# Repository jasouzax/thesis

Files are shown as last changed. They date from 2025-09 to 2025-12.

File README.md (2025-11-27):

# Thesis of Jasouza
 
 
[]() 
 
 
 

Development of Visual [Sensory Substitution Device](https://en.wikipedia.org/wiki/Sensory_substitution) for the visually impared especially the blind, through incorporating three novel ideas to solve issues of existing solutions: Virtual World Mapping, Emulating Human Sensoring, and Adaptable Modular System
- [Title](#title)
- [Background of the Study](#background-of-the-study)
- [Rationale](#rationale)

### Summary
1. **Identifying a Problem**  
   The thesis identifies a problem aligned with global frameworks, such as the Sustainable Development Goals (SDGs), to ensure relevance and real-world impact. Specifically, it focuses on **SDG 10: Reduced Inequalities**, which targets disparities based on factors like income, age, sex, disability, race, ethnicity, origin, religion, or economic status. To narrow the scope, the work concentrates on **disability inequalities, with an emphasis on visual impairments** (e.g., blindness or low vision, affecting over 2.2 billion people per WHO estimates).

2. **Identifying the Objective**  
   Drawing from SDG 10, the primary objective is to **minimize inequalities faced by visually impaired individuals**. These fall into two major, often overlapping categories:  
   - **Navigational inequalities**: Barriers in physical and digital infrastructure not designed for accessibility (e.g., buildings without tactile guides or websites lacking audio alternatives).  
   - **Social inequalities**: Limitations in communication, societal status, or workforce participation (e.g., reduced job opportunities due to inaccessible tools or stigma in social interactions).  
   Note that inequalities are not strictly binary; for instance, job opportunities can involve both navigational challenges (e.g., vision-dependent tasks) and social ramifications (e.g., financial limitations from restricted options), aligning with SDG targets like 10.1 (reducing income inequalities through broader employment access), 10.2 (promoting social, economic, and political inclusion), and 10.3 (ensuring equal opportunities despite barriers like discrimination).

3. **Identifying a Solution**  
   Approaches to addressing these inequalities are not mutually exclusive and can blend elements, though they often prioritize one aspect:  
   - **Assistive technologies**, which primarily extend existing capabilities (e.g., canes, guide dogs, or braille displays).  
   - **Substitution technologies**, which primarily represent missing senses through alternatives (e.g., screen readers or sensory substitution devices that convert visual data to audio/tactile feedback).  
   The thesis prioritizes the **substitution approach** due to its potential for comprehensive impact on the identified objectives, enabling more independent navigation and interaction, while acknowledging that hybrid solutions may incorporate assistive elements.

4. **Identifying the Issues**  
   Substitution technologies, particularly sensory substitution devices (SSDs), encounter significant, interconnected challenges generalized as **sensory limitations**:  
   - **Sensory overload**: When translated information exceeds the brain's processing capacity.  
   - **Sensory fatigue**: Prolonged use leading to mental exhaustion.  
   - **Sensory integration**: Difficulty in learning or subconsciously interpreting the substituted signals.  
   These stem from the core limitation of representing one sense through another and must be addressed for effective adoption.

5. **Identifying our Hypothesis**  
   Inspired by human psychology—where perception is **selective rather than raw data intake**—the hypothesis posits that SSDs can minimize sensory limitations by making the process **controllable**. This allows the brain to build subconscious patterns efficiently. For the prototype, users could control the "focus" of emulated vision via **silent, quick inputs like hand gestures**, mimicking eye muscle adjustments. However, the core focus is on controllability itself, with the method being modular (e.g., adaptable to voice, head tilts, or eye-tracking for users with varying abilities) to suit the hypothesis without restricting to one input type.

6. **Identifying the Tests**  
   To validate the hypothesis, evaluate the device's efficiency in mitigating sensory limitations through a mix of quantitative and qualitative metrics:  
   - **Sensory overload**: Measure user accuracy in interpreting generated audio cues (e.g., via task completion rates) and qualitative feedback on perceived overload.  
   - **Sensory fatigue**: Assess usage duration before symptoms like headaches emerge (e.g., via self-reported scales, physiological monitoring, or user surveys).  
   - **Sensory integration**: Track reaction times to environmental data, learning curves over sessions, and survey responses on ease of subconscious adaptation.  
   - **Device performance**: Test accuracy in recognizing user controls (e.g., hand gestures) and generating relevant audio from environmental inputs.  
   Evaluations will include comparisons to baselines from related literature on existing SSDs, incorporating user-centered qualitative insights (e.g., surveys) to account for individual experiences.

7. **Identifying the Impact**  
   If successful, the device could substitute visual information as audio via a **modular pipeline**, enabling extensions for diverse needs (e.g., customizable adaptations for varying lifestyles or impairment levels). This would reduce navigational inequalities (e.g., accessible OS and environments for better job opportunities) and social inequalities (e.g., enhanced communication tools), contributing to SDG 10 targets such as 10.1 (income growth via expanded employment), 10.2 (empowerment through regained navigational and social inclusion), and 10.3 (equal opportunities in workforce and society). While not resolving all issues (e.g., medical treatments or systemic discrimination), it demonstrates the possibility of partially minimizing sensory limitations—evidenced by test results showing users can interpret data with reduced overload, fatigue, or integration challenges—paving the way for applications to other sensory disabilities.

8. **Identifying the Scope and Limitations**  
   The thesis prioritizes proving the hypothesis—that sensory limitations can be partially addressed through selective, controllable substitution—rather than perfecting the device or developing all extensions. By completion, the output will be a prototype SSD that emulates visual perception as audio, minimizes limitations, and features a modular pipeline for future enhancements (e.g., alternative controls). Limitations include assumptions of basic user abilities for prototype inputs, focus on visual-to-audio substitution only, and recognition that tech complements broader efforts like policy changes for full inequality reduction.

<!--
## Summary
- [**Problem**](https://pmc.ncbi.nlm.nih.gov/articles/PMC5044782) - Issue facing visual sensory substitution devices in widespread adoption that being **cognitive overload** and **limited generaliziblity**.
- **Solution** - To **emulate human visual attention** to solve cognitive overload, and to implement a **virtual navigatable world system** to solve limited generaliziblity.
- **Hypothesis** - Would emulating *human visual processes* to minimize substituted information and implementing *navigation techniques to virtual worlds (physical and digital)* prevent cognitive overload, allow subconscious sensory augmentation, and help integrate visually impared individuals in the physical and digital aspects?
   - [**Null Hypothesis**](https://en.wikipedia.org/wiki/Null_hypothesis) $H_0$ - The solution we implemented provided did not prevent cognitive overload nor help individuals navigate both physical and digital worlds.
   - **Alternative Hypothesis** $H_1$ - The solution we implemented forwarded the progress of sensory substitution devices by solving the two issues facing most sensory substitution devices.
   - **P-Value Testing** - Quantitative testing such has accuracy of individual's pointing to direction of movement, and Qualitative testing (Focus Group Discussion (FGD)) such as how much of them sense through the device subconsciously.

## Timeline to take note of
Vietnam field trip, Service Learning, and [Robothia Conference on Robotics and Technologies](https://www.ihsanyassin.com/cms/conference.php?conf_id=883736a8-1285-42f8-95f5-dd1f653de3f6)
- `Nov 24, 2025` - Service Learning 1st Seminar
- `Dec 01, 2025` - Robothia 2026 Deadline of paper submission 
- `Dec 03, 2025` - Service Learning 2nd Seminar
- `Dec 05, 2025` - Field trip Vietnam
- `Jan 14, 2026` - Service Learning 3rd Seminar
- `Jan 15, 2026` - Robothia 2026 Start of acceptance notification
- `Feb 01, 2026` - Robothia 2026 Camera-Ready Deadline
- `Apr 11, 2026` - Robothia 2026 Start and End of Conference

## Todos
- [ ] Contact visually impared organization for research testing like [NCDA](https://ncda.gov.ph/iloilo/) and [Resources for the Blind](https://blind.org.ph/)

## Title
> World Navigation Hat - Development of a Wearable Navigation Aid using AIoT for the Visually Impaired
<details>
   <summary><a href="https://www.thesavvyscientist.com/thesis-title-examples">Target</a></summary>
   
   - **Make it descriptive of the research so it’s immediately obvious what it is about!** - It's a visual sensory substitution device but not much people understand what that means so just use **"Wearable Navigation Aid"**, and although the main feature is it's visual substitution mostly use full for the full blind, it additionally incorporates other visual independent assists which can be useful for people with a variety of visual impairments thus use **"Visually Impaired"**
   - **Don’t get lost in the detail** - Our device incorporates multiple methods to achieve the goal such as manual algorithms *(world mapping, emulating senses, priority audio cueing, etc.)*, artificial intellegence *(hand gesture recognition, voice recognition, face recognition, etc.)*, and IoT *(central server for API and automation, world tracking through sensors like GPS, IMU, etc.)*. To summarize the whole process we will just use **"AIoT"** to summerize/generalize the whole process
   - **The title should tie together the chapters of your thesis** - The thesis will primarly be about the creation and testing of this device thus use **"Development"**, however since our thesis is a prototype mainly focusing on the hardware and software aspect to solve the issue the final prototype will be bulky to be worn has an eyewear so the paper will be taking into account the device has a hat instead to put all of that load in the head instead of sensitive areas like eyes and ears, thus use **"Hat"**
   - **Be strategic** - The main feature of our thesis, is to solve the inequality the visually impared faces when they participate in society, such has navigating the physical world *(going from one place to another especially if the infastructure is not designed for them in mind)*, and the digital world *(social media, internet, etc.)* thus use **"World Navigation"**
</details>

## Background of the Study
### Targets *([ref](https://www.enago.com/academy/what-is-background-in-a-research-paper))*
1. **Provide background information** - The background of the study must contain the following to provide enough background information on what this paper will be talking about
   - Provide the statistical information about the number of people affected with the variety of visual impairments in a global, national, and regional scale
   - Provide the description of what a Sensory Substitution Device are in helping the visually impared and they current issue
1. **Identify Your Audience** - Our audience in reading the paper includes students, teachers, and reviewers so we will discuss the project in technical detail
2. **Understand the Research Problem** - The research aims to solve the issues faced by current Sensory Substitution Devices primarily Cognitive overload and limited gneralization beyond labs
3. **Review Existing Literature** - Existing literature
4. **Include Historical Data**
5. **Identify Controversies and Gaps**
6. **Select Key Components**
7. **Craft a Logical Flow**
8. **Hightlight the Novelty of Your Research**

## Rationale
Our approach is justified to forward the progress of sensory substitution devices and attempt to see if we could overcome the issues they faced in societal wide implementation. Our unique approach is to implement three major solutions with a design decision:
- **Virtual worlds** that keep track of the Physical and Digital world allowing the user to navigate not just the physical world but the internet, social media, offline files, etc.
- **Emulation of Human Sensory Processes** to create a more intuitive and less cognitive overloading or sensory fatigue system for users to view the world in
- ***Modularity system** connected into a IoT server, has there are different kinds of visual impairments and everyone have different needs or preferences thus the system must allow customization for each individual which is done through the implementation of Applications
- **Hat** has a prototype is bound to be bulky which can be temporarily solved by putting weight on the head rather then more sensitive areas like eyes or ears until we could compress it into an eyewear

Background of Study
- State how visual imparement
Explain visual sensory substitution and its relevance to the visually impaired, discuss its relevance to School, Regional, National, and international interest through data and sources

Problem Statement
- Explain in detail the issues of
  - the visually impaired or the blind navigating the world without clear sight with their options
  - being limited in detail (white canes, guide dogs, etc.)
  - gap in advance solutions (smart devices, sensory substitution devices, etc.)
  - how existing sensory substitution device have problems with generalization beyond labs, user comfort and ergonomics, cognitive overload, training and intuitiveness, and processing constraints of sensory system

Rationale
- 

Objectives

## Materials and costs
| Quantity | Material | Total Cost |
| - | - | - |
| 1 | Raspberry PI Zero 2W | &#8369;1,280 |
| 2 | OV5640 USB Camera 5MP and 160&deg; FOV | &#8369;2,500 |
| 1 | TRRS 3.5 Jack Breakout | &#8369;25 |
| 1 | Type-C 5A/3A 18650 Lithium Battery UPS | &#8369;121 |
| 1 | Stereo Earphone | &#8369;101 |
| 1 | MPU6050 | &#8369;102 |
| 1 | SIM868 GSM GPRS GPS | &#8369;660 |
| 2 | 18650 Lithium Battery | &#8369;70 |
**TOTAL:** &#8369;4,859
-->

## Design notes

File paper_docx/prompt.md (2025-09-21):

With this incomplete paper template I have to restart with a new template, please rewrite this paper to (with citations):

* **Background of the Study** - Please bring up the statistics of the visually impared by types *(fully blind, near sighted, far sighted, etc.)* and by place *(globally, philippines, and in Iloilo if possible)*. Explain what visual sensory substitution devices are and how it could help the visually impared, their reasons why they arent globally used by the visually impared *(e.g: cognitive overload, training and intuitiveness, ergonomics, processing constrains of sensory systems, etc. but summarized has it will be mostly in Rationale)*. Our attempts to solve it through three major solution in the attached document *(Not that specific cause most will be in Rationale)*, and our final objective to foward the process of Sensory Substitution Device and attempt to see if we could overcome the issues they faced in societal wide implementation
* **Rationale** - In here explain in full detail the existing issues or knowledge gap in Sensory Substitution Devices mostly specifically in Visual Substitution, and how solving this issues would greately improve the lives of the Visually impared people especially the fully blind has it would help them navigate the Physical and Digital worlds. And here fully specify the solutions we implemented that seperates us from existing research papers.
* **Objectives of the Study**

  * **General Objective** - Here just specify our generate objective I provided in the paper template, the objective to build the Visual sensory substitution device through our methods
  * **Specific Objectives** - Here specify our two specific objectives I also provided in the paper template of the Physical World and the Digital World

* **Significance of the Study** - Here explain issues the visually impared especially the blind face in navigating the physical and digital world, especially in the Philippines. Specify what solutions have been made for them like Mobility aids, Digital Accessibility Tools, etc. But explain the remaining issues like Public implementation *(Our device converts visual information to audio such that when society doesnt fully support braille or blind support our device could translate nessary information ensuring the blind doesnt fully depend on blind support)*, Cost *(Our device should be cheaper then the phone has it is ment to be the Blind's man phone)*, Inconsistent implementations in WCAG/ADA *(Our application uses automation/APIs to interact with external sources reducing dependencies of the blind in blind support websites/apps, etc.)*
* **Conceptual Framework** - I am not sure what this should be about, but our device's variables include images from the two cameras, depth and color information from applying stero computations with the two cameras *(5MP 160deg, 10cm apart)*, audio data from the speaker, user orientation from the IMU, the point cloud output from the computation is then scalled and map to a virutal digital map, nessary information is either directly outputed to speaker like voice information or processed as a spectrogram like depth information (frequency represents Y-axis, binaural audio represents X-axis, volume represents depth or Z-axis, focus point is located at the center of the image infront of user, focus radius is inversely proportional to focus point change speed which is mostly biased on the X-axis has objects near the top or bottom of the user is more important thus the focus shape is more of a tall oval, etc. variables should match human visual/sensory theories like logarithmic scalling or focus scopping, etc)
* **Theoretical Framework** - I am also not sure what this should be about, but our research is based on the theory of human cognitive senses like logarithmic scalling or focusing scopping, but also theorizes that by prioritizing emulating human cognitive processes/illusions/etc. we could solve (Sensory Substitution Devices)SSD's problem of sensory overload or fautigue, and could also solve different generalized situtations by making the underlying system modular for the user's personal interest/wants
* **Scope and Delimitations** - Include what was stated in the paper, our research specifically focusing on creating a visual sensory substitution device so we must prioritize on ensuring that the visual information can be interpreted through audio, then we can focus on ensuring the underlying system is modular for more processes the user wants and that the device could keep track of the physical and digital world
* **Related Studies** - Here include related studies that could assist with our paper, and the summary of what they could provide for our research
* **Review Literature** - Here review relateed studie's process, outcome, materials, etc. with relation to our research
* **Research Design/Methods** - Reference from the provided paper
* **Materials and Processes** - Reference from the provided paper
* **Hardware Material Specification** - Reference from the provided paper
* **Software Specification** - Reference from the provided paper
* **Library and Board Managers** - Reference from the provided paper
* **Other Materials/Equipment/Device** - Reference from the provided paper

Please include the sources/citations for whatever is stated, use the provided/attached paper and the document to understand our research, you can improve whatever is on the paper or what I described in each bulletin points but ensure the final contains the exact bultin points I provided

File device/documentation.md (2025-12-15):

1. Download `calibration.py` to computer
2. Connect the two stereo cameras to computer
3. Run the script to find the best baseline distance and generate the calibration data
4. Get a micro SD Card
5. Install Orange PI OS for our microcontroller at [orangepi.org](http://www.orangepi.org/html/hardWare/computerAndMicrocontrollers/service-and-support/Orange-Pi-Zero-2W.html)
6. Connect the Orange PI Zero 2W with micro SD Card and expansion board
7. Connect the router's LAN to the expansion board
8. The repository

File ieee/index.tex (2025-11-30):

% ------ IEEE Paper ----- %
\documentclass[conference]{IEEEtran}
\IEEEoverridecommandlockouts

% ----- SUMMARY ----- %
\iffalse
    1. **Identifying a Problem**  
    The thesis identifies a problem aligned with global frameworks, such as the Sustainable Development Goals (SDGs), to ensure relevance and real-world impact. Specifically, it focuses on **SDG 10: Reduced Inequalities**, which targets disparities based on factors like income, age, sex, disability, race, ethnicity, origin, religion, or economic status. To narrow the scope, the work concentrates on **disability inequalities, with an emphasis on visual impairments** (e.g., blindness or low vision, affecting over 2.2 billion people per WHO estimates).
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
    These stem from the core limitation of representing one sense through another and must be addressed for effective adoption.

    5. **Identifying our Hypothesis**  
    Inspired by human psychology—where perception is **selective rather than raw data intake**—the hypothesis posits that SSDs can minimize sensory limitations by making the process **controllable**. This allows the brain to build subconscious patterns efficiently. For the prototype, users could control the "focus" of emulated vision via **silent, quick inputs like hand gestures**, mimicking eye muscle adjustments. However, the core focus is on controllability itself, with the method being modular (e.g., adaptable to voice, head tilts, or eye-tracking for users with varying abilities) to suit the hypothesis without restricting to one input type.

    6. **Identifying the Tests**  
    To validate the hypothesis, evaluate the device's efficiency in mitigating sensory limitations through a mix of quantitative and qualitative metrics:  
    - **Sensory overload**: Measure user accuracy in interpreting generated audio cues (e.g., via task completion rates) and qualitative feedback on perceived overload.  
    - **Sensory fatigue**: Assess usage duration before symptoms like headaches emerge (e.g., via self-reported scales, physiological monitoring, or user surveys).  
    - **Sensory integration**: Track reaction times to environmental data, learning curves over sessions, and survey responses on ease of subconscious adaptation.  
    - **Device performance**: Test accuracy in recognizing user controls (e.g., hand gestures) and generating relevant audio from environmental inputs.  
    Evaluations will include comparisons to baselines from related literature on existing SSDs, incorporating user-centered qualitative insights (e.g., surveys) to account for individual experiences.

    7. **Identifying the Impact**  
    If successful, the device could substitute visual information as audio via a **modular pipeline**, enabling extensions for diverse needs (e.g., customizable adaptations for varying lifestyles or impairment levels). This would reduce navigational inequalities (e.g., accessible OS and environments for better job opportunities) and social inequalities (e.g., enhanced communication tools), contributing to SDG 10 targets such as 10.1 (income growth via expanded employment), 10.2 (empowerment through regained navigational and social inclusion), and 10.3 (equal opportunities in workforce and society). While not resolving all issues (e.g., medical treatments or systemic discrimination), it demonstrates the possibility of partially minimizing sensory limitations—evidenced by test results showing users can interpret data with reduced overload, fatigue, or integration challenges—paving the way for applications to other sensory disabilities.

    8. **Identifying the Scope and Limitations**  
    The thesis prioritizes proving the hypothesis—that sensory limitations can be partially addressed through selective, controllable substitution—rather than perfecting the device or developing all extensions. By completion, the output will be a prototype SSD that emulates visual perception as audio, minimizes limitations, and features a modular pipeline for future enhancements (e.g., alternative controls). Limitations include assumptions of basic user abilities for prototype inputs, focus on visual-to-audio substitution only, and recognition that tech complements broader efforts like policy changes for full inequality reduction.
\fi

% ----- PACKAGES ----- %
\usepackage{cite}
\usepackage{amsmath,amssymb,amsfonts}
\usepackage{algorithmic}
\usepackage{graphicx}
\usepackage{textcomp}
\usepackage{xcolor}
\usepackage{makecell}

% ----- STYLING ----- %
\def\BibTeX{{
    \rm B\kern-.05em{\sc i\kern-.025em b}\kern-.08em
    T\kern-.1667em\lower.7ex\hbox{E}\kern-.125emX
}}
\begin{document}

% ------ DOCUMENT ----- %
\title{World Navigation Hat - Development of a Wearable Navigation Aid using AIoT for the Visually Impaired}

% ----- AUTHORS ----- %
\author{
    \IEEEauthorblockN{Jason C. D'Souza}
    \IEEEauthorblockA{
        \textit{Department of Computer Engineering}\\
        \textit{University of San Agustin}\\
        Iloilo City, Iloilo, Philippines \\
        jasouzax@gmail.com \\
        ORCID: 0009-0003-6062-7921
    }
    \\
    \IEEEauthorblockN{Vince Ginno B. Daywan}
    \IEEEauthorblockA{
        \textit{Department of Computer Engineering}\\
        \textit{University of San Agustin}\\
        Iloilo City, Iloilo, Philippines \\
        vgbalitao-saan@usa.edu.ph
    }
    \and
    \IEEEauthorblockN{Ethel Herna C. Pabito}
    \IEEEauthorblockA{
        \textit{Department of Computer Engineering}\\
        \textit{University of San Agustin}\\
        Iloilo City, Iloilo, Philippines \\
        ehpabito@gmail.com
    }
    \and
    \IEEEauthorblockN{ChenLin Wang}
    \IEEEauthorblockA{
        \textit{Department of Computer Engineering}\\
        \textit{University of San Agustin}\\
        Iloilo City, Iloilo, Philippines \\
        cwang@usa.edu.ph
    }
    \\
    \IEEEauthorblockN{Glenda S. Guanzon}
    \IEEEauthorblockA{
        \textit{Department of Computer Engineering}\\
        \textit{University of San Agustin}\\
        Iloilo City, Iloilo, Philippines \\
        gguanzon@usa.edu.ph
    }
}

% ----- TITLE ----- %
\maketitle

% ----- ABSTRACT ----- %
\begin{abstract}
    % 150–250 words. Summarize purpose, methods, results, and conclusions. No citations, math, symbols, or footnotes.
    Our primary objective is aligned with Sustainable Development Goal (SDG) 10 on reducing inequalities, specifically to mitigate disparities faced by visually impaired individuals (VIP) by addressing a key challenge in sensory substitution devices (SSDs): sensory limitations. We hypothesize that enabling user-controlled selection of substituted sensory information via intuitive inputs like hand gestures could facilitate efficient subconscious pattern-building in the brain, thereby minimizing overload, fatigue, and integration issues. To test this, we developed a wearable prototype using a Raspberry Pi 5 equipped with a UPS, IMU sensor, camera, and earphones, designed as a head-mounted ``hat'' to distribute weight away from sensitive facial areas. The system generates depth maps using MiDaS AI for environmental perception, recognizes hand gestures via MediaPipe AI for user control, and employs a novel algorithm to produce targeted audio channels representing selective visual data by emulating human sensory processes in psychology, plus a primitive connection to a server through NodeJS for future modular features. Validation involved empirical assessments of sensory limitations through metrics including sensory overload (e.g., interpretation accuracy), fatigue (e.g., sustainable usage duration), integration (e.g., reaction times and learning curves), and overall device performance. Extensive optimizations were required, such as model downscaling, information chunking into digestible segments, and consideration of alternatives like stereo vision to enhance real-time efficiency. Results indicate that users favored brief, intermittent audio outputs over prolonged sessions, demonstrated improved environmental perception, and experienced reduced sensory limitations. In conclusion, our approach partially resolves SSD challenges, validating the potential of controllable substitution, though further refinements and longitudinal studies are essential for broader applicability and impact on SDG 10 targets.
    %Our primary goal is drawn from Sustainable Development Goals (SDG) 10 about disability, more specifically, to minimize inequalities faced by the Visual Impaired People (VIP), by solving an prominant issue called Sensory Limintation facing the development of Sensory Substitution Devices (SSD), through our hypothesis of allowing the selection of substituted information to be controlled directly by the user like from hand gestures to allow the brain to build subconscious patterns efficently. We used a raspberry pi 5 to store our program with a UPS, IMU, camera, and earphone as a wearable Hat to transfer load to the head rather than sensitive areas like eyes, ears, and nose. Our prgrogram generates a depth map through MiDaS and recognizes hand gesture through MediaPipe, and generates the audio channels based on our novel algorithm. To validate our hypothesis we evaluate the device's efficiency in mitigating core issues of Sensory Limitations through empirical metrics such as Sensory overload, Sensory fatigue, Sensory integration, and Device performance. During testing we had to heavily optimize our program by downscalling the models like even planned to switch to Stereo vision instead of MiDaS, or split the translated information into digestable bites. The results show that users prefer to use short periods of audio output rather than perlong use, are able to percive the environment, and show minimized effect of sensory limitation. In conclusion, we are partially able to solve the sensory limitation issue but more improvements and follow up studies are needed.
\end{abstract}
\begin{IEEEkeywords}
    sensory substitution device, SDG 10, visual impairment, controllability, accessibility, assitive robotics, industrial automation
\end{IEEEkeywords}

% ----- INTRODUCTION ----- %
\section{Introduction}
% Introduce the problem (SDG 10 focus on disability inequalities, WHO stats on 2.2B visually impaired), objective (minimize navigational/social barriers), hypothesis (controllable substitution reduces sensory limitations), and paper outline. Tie to conference theme (Assistive Robotics and Accessibility).
% Problem Source (SDG 10)
Visual impairment is a global health problem that significantly affects individual's daily lives by impeding independent navigation, social interaction, and overall quality of life \cite{b1}. There is an estimation of 2.2 billion people globally who are identified as visually impaired and this number could still increase to 2.5 billion by 2050 as stated by the World Health Organization \cite{b2}. This thesis focuses on SDG 10, which aims to reduce inequalities within and among countries based on income, sex, age, disability, sexual orientation, race, class, ethnicity, religion, and oppotunity \cite{b3}. More specifically our thesis focuses on visual impared people or VIPs under disability, VIPs does not pertain to total blindness and can be identified and categorized based on presenting visual acuity \cite{b2}.

% Solutions
Navigation is one of the problems VIPs encounter; they often have difficulty crossing the road and tracking their location, as well as experiencing accidents, falls, and collisions \cite{b4}. In addition, VIPs experience social isolation and reduced access to information, limiting their educational and employment opportunities \cite{b5}. There are already existing solutions or aids for VIPs, for daily assistance, which include guide dogs, white canes, and electronic travel aids \cite{b4}. Additionally, one of the technologies VIPs depend on for navigation is assistive devices, which use sensory substitution to convert visual information into auditory or tactile cues to provide spatial awareness often incorporate IoT sensors to capture real-time environmental data, providing navigational assistance in complex environments \cite{b6}.

% Issues with solutions
Sensory substitution devices or SSDs are assistive wearable devices that can be eyewear, a vest, or a hat, allowing VIP users to perceive their surroundings by converting sensory information from one modality to another \cite{b7}. For our thesis we will focus on developing a SSD that is a hat. These SSDs are embedded with sensors that allow obstacle detection, navigation, and object recognition, enhancing VIPs' daily independence and reducing their reliance on traditional aids \cite{b8}. However, global adoption of these devices is limited due to cognitive overload performance, extensive training needs, ergonomic discomfort design, and the lower processing bandwidth of non-visual senses compared to vision \cite{b9}. This is what our thesis will focus on, to experiment to see if by implementing controllable selective substitution that we could overcome this sensory limitation.

\subsection{Problem Identification}
% Detail SDG 10 targets (10.1–10.3), focus on visual impairments, navigational (e.g., inaccessible infrastructure) vs. social inequalities (e.g., employment stigma).
% Problem Source in summary
This thesis addresses a global problem aligned with the United Nations Sustainable Development Goal (SDG) 10, which is to reduce inequalities within and among countries based on income, sex, age, disability, sexual orientation, race, class, ethnicity, religion, and oppotunity \cite{b3}. Specifically, our target problem is to make it possible for visually impaired persons (VIPs) to have approximately the same level of opportunities as the general population \cite{b10} by minimizing the major limitations currently faced by sensory substitution devices (SSDs), thereby contributing to the achievement of several SDG 10 targets.

% Problem Source Tagets in detail
%SDG Target 10.1 aims to achieve and sustain income growth for the bottom 40\% of the population at a rate higher than the national average \cite{b11}. Improved sensory substitution devices (SSDs) can directly support this by expanding job opportunities for visually impaired individuals, thereby reducing income inequality \cite{b12}. Target 10.2 seeks to empower and promote the social, economic, and political inclusion of all irrespective of disability \cite{b11}; effective SSDs contribute by enabling visually impaired people to perform tasks and interact beyond their current sensory limitations \cite{b13}. Target 10.3 calls for ensuring equal opportunity and reducing inequalities of outcome through the elimination of discriminatory practices \cite{b11}; better SSDs help by providing practical capabilities that allow visually impaired individuals to access opportunities currently out of reach \cite{b14}. Target 10.4 encourages the adoption of fiscal, wage, and social protection policies to achieve greater equality \cite{b11}; when SSDs improve employability and workforce participation, they strengthen both the evidence and societal demand for such inclusive policies \cite{b15}. The remaining targets (10.5--10.b), which address global financial regulation, official development assistance, and migration policies, fall outside the direct scope of a technology-focused SSD intervention.
%SDG Target 10.1 seeks to progressively achieve and sustain income growth of the bottom 40\% of the population at a rate higher than the national average \cite{b11}; this can be supported by providing visually impaired individuals with wider job opportunities through improved SSDs, which in turn reduces income inequality \cite{b12}. Target 10.2 aims to empower and promote the social, economic, and political inclusion of all, irrespective of disability \cite{b11}; this can be assisted if visually impaired people are enabled to perform tasks and interact beyond their current sensory limits \cite{b13}. Target 10.3 calls for ensuring equal opportunity and reducing inequalities of outcome by eliminating discriminatory laws, policies, and practices \cite{b11}; this is supported by giving visually impaired individuals practical capabilities (via better SSDs) to seize existing opportunities that are currently inaccessible \cite{b14}. Target 10.4 focuses on adopting policies, especially fiscal, wage, and social protection policies, to progressively achieve greater equality \cite{b11}; improved employability and workforce participation of visually impaired persons made possible by effective SSDs would strengthen the evidence base and societal pressure for such inclusive policies \cite{b15}. Targets 10.5 to 10.b (regulation of global financial markets, ODA, migration policies, etc.) lie outside the direct scope of an SSD-focused technological intervention.

%Specifically our target problem is to make it possible for VIPs to have approximately the same level of opportunities with the general population though minimizng the issues that SSDs faced so that the SDG 10 targets could be assisted. SDG 10 Target like Target 10.1 about achieving and sustaining income growth of the bottom 40\% which could be assisted if the disabled have more job opporunities to earn income, or Target 10.2 to empower and promote inclusion for all which could be assisted if the disabled could do more beyond their initial limits, or Target 10.3 about ensuring equal opportunities by providing them the capabilities to act on those opportunities, or Target 10.4 to adopt policies and progressively achieve greater equality which could be assisted if the disabled have a larger impact in the workforce, while Target 10.5--10.b are more out of our scope in minimizing inequalities in the disabled. 

% Inequality and problem
The inequalities the VIPs faced we specifically focused on are two major but often overlapping categories: navigational and social \cite{b16}. Navigational inequalities which are barriers in physical and digital infrastructure not designed for accessibility such as building that lack tactile guides or website and software without audio alterantives \cite{b17}. Social inequalitities which are limitations in communication, societal status, or workforce participations, for instance only about 44\% of visually impaired individuals are employed compaired to 79\% of those without disabilities, often due to employer attitudes and lack of accommodations \cite{b18}. These two categories of inequalities could be minimized if the VIPs partially have the ability they lack, this could be achieved through Sensory Substitution Devices \cite{b19}.

\subsection{Research Objectives and Contributions}
% State primary goal: Reduce inequalities via substitution tech; highlight novelty in controllability for selective perception.
% Development of SSD
The primary objective of this research is to minimize inequalities for visually impaired individuals by developing and testing substitution technologies, specifically sensory substitution devices (SSDs) that convert visual information into accessible formats like audio, thereby enabling more independent navigation and social interaction \cite{b4}. This approach prioritizes substitution to address core sensory gaps holistically, while acknowledging potential hybrids with assistive elements, and aligns with SDG 10 by promoting economic inclusion through expanded job opportunities (Target 10.1), empowerment via regained access and participation (Target 10.2), and equal opportunities by reducing discriminatory barriers (Target 10.3) \cite{b3}.

% Novel Idea
The key novelty in solving the sensory limitation issues that SSDs face is through incorporating controllability for selective perception \cite{b20}. This idea is inspired by psychological principles where the human sense filters relevant information to avoid overload \cite{b21}. To accomplish this our device should allow the sensory translation to be controlled by the user like through hand gestures, allowing realtime customization of translation and addressing the Sensory limitation issue of SSDs like overload, fatigue, or integration \cite{b9}. By demonstrating that this is possible, it could pave the way for scalable applications to other sensory disabilities, enhanching the fields of assistive technology with user-centered, efficient substitution framework \cite{b22}.

% ----- RELATED LITERATURE  ----- %
\section{Related Work}
% Review existing solutions: Assistive (e.g., canes, braille) vs. substitution tech (e.g., screen readers, SSDs converting visual to audio/tactile). Discuss issues (sensory overload/fatigue/integration) from literature. Compare to your approach (hybrid with controllability). Cite 5–10 sources.
% Existing solutions
There are existing solutions in providing VIPs a way to navigate the world, but from our research there are two major overlapping categories of these solutions which are Assistive and Substitution technologies \cite{b4}. Assistive technologies which primarily extend existing capabilities such as canes, guide dogs, or braille displays \cite{b26}. Substitution technology which primarily represent missing senses through alternatives such as screen readers and sensory substitution devices that convert visual data to audio feedback \cite{b20}. Since our thesis aims to minimize inequalities of the VIPs by providing them a way to navigate the physical and digital world so that they could have approximately the same opportunities as the general population, we focused on Substitution technology, more specifically visual substitution devices \cite{b27}.

\subsection{Assistive and Substitution Technologies}
% Overview of prior SSDs; pros/cons (e.g., overload in raw data conversion).
% Designing sensory-substitution devices: Principles, pitfalls and potential
Reference \cite{b20} designs their SSD for blindness using touch and audio, similarily following design princicples like task-focused information conveyance to avoid redundancies and match the sensory bandwidths, highlighting the issues faced by SSDs like sensory overload from exessive data so there must be a selective process of key environmental cues to mitigate it. The bandwidth mismatches does lead to persistent fatigue and high training requirements delay usability and integration.
% Efficiency of Sensory Substitution Devices Alone and in Combination With Self-Motion for Spatial Navigation in Sighted and Visually Impaired
%Reference \cite{b23} evaluates existing SSDs like vOICe which represents information as audio cues, and BrainPort which represents information as tactile for navigation in VIPs. It addresses sensory overload as a barrier in dual SSD due to high cognitive load, suggesting that longer training is needed for automatical or subconscious processing. Similar to our thesis, it suggested that selective processing is needed in the device designs with psychological principles. However inital dual-use increase fatigue without extended training, challenging for less experienced users.
Reference \cite{b23} introduces a multi-device combination SSD, lowers overload by distributiong cognitive load, enchances integration through perceptual reweighting, and improving long-term navigation accuracy. The initial dual-use however, increases fatigue without extended training, highlighting integration challenges for less experienced users.
% Sensory substitution of vision: Importance of perceptual and cognitive processing
Reference \cite{b24} reviews vision substitution via hearing and touch, implements preprocessing filters to reduce overload by focusing on essential data, plasiticity aids long-term integration, and enables better nativation equity. The bandswith limits still causes persistent information loss and fautigue, often struggling with controllability and requires user adaption.
% Design and Development of a Sensory Substitution System for the Visually Impaired
Reference \cite{b25} device similarly is also a wearable portable smart hat, is low-cost, minimizes navigational inequalitiess, and provides real-time feedback to improve integration and learning. It lacks selective processing and can lead to sensory overloading in cluttered environments and can cause fautigue over prolonged use.

\subsection{Gaps in Addressing Sensory Limitations}
% Highlight how current SSDs lack user control, leading to fatigue; position your hypothesis as a solution.
These SSDs highlights and face a common issue which we can generally call as Sensory Limitation, these include sensory overload where the translated information is just too much for the user to actually process either through auditory bandwidth limit or interferance, sensory fautigue where hearing audio repetively can cause discomfort and less sensory perception, and finally sensory integration where the translated audio representation cant be subconsciously integrated by the user's perception of their environment making learning harder and daily use tiring \cite{b20}. Our thesis aims to minimize sensory limitation through high controllable selective translation where specific environment cues can be selectively filtered by the user directly and for any period of time, minimizing overload, fautigue, and allowing more controllable integration like allowing modular learning when using it for the first time \cite{b23}.

% ----- PROPOSED APPROACH ----- %
\section{Methodology}

\begin{figure}[htbp]
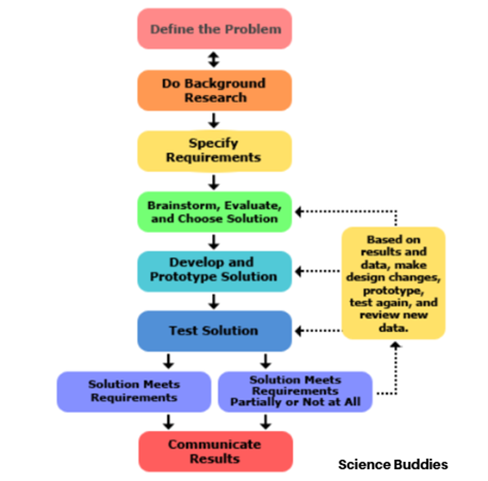
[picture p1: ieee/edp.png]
    \centerline{}
    \caption{Engineering Design Process}
    \label{edp}
\end{figure}
The method for this study follows the engineering design process as seen in figure \ref{edp}, we defined the problem by aligning it with SDG 10 and limited the scope to visual imparities, we did background research on solutions like sensory substitution devices. specified the requirements to test our hypothesis, brainstorm a way to accomplish it, develop and prototype the device, test and see if it fulfilled our hypothesis, brainstorm again when the hypothesis doesnt align, else communicate the results.

\subsection{Hypothesis and Design Principles}
% Describe the solution: Substitution-focused SSD with controllability (e.g., hand gestures for focus adjustment, mimicking eye movements). Explain modular pipeline (visual input → processing → audio output, adaptable inputs like voice/head tilts). Include equations if needed (e.g., for signal processing: $a + b = \gamma$ for simplified audio mapping).
Following the theoretical principle that human visual perception has a focus and special resolution \textit{Foveation} \cite{b28}. Our approach is to generate a depth map from a camera using MiDaS, the hand guesture is also captured from the same camera image using MediaPipe. The hand gesture specifically the back of the right hand determines what is to be exectuted by the command, for this instance it has a few pre-installed gestures:
\begin{itemize}
\item \textbf{Open hand gesture} which translates the depth map into audio by cycling between right and left side where each slice of the image is translated into audio with the vertical position representing frequency and depth/proximiting representing volume represented by the equation
    \begin{equation}
    A_c(T, s) = \sum_{n=0}^{B-1} \frac{D_{t(T)}\left[B-1-n\right]}{255\times 10} \cdot G_c(t(T)) \cdot \sin\left(2\pi f_n \frac{s}{R}\right) \label{out_open}
    \end{equation}
    Where:
    \begin{itemize}
        \item $c$ - Channel number, $0$ for right and $1$ for left
        \item $A_c$ - Audio output for channel $c$
        \item $T$ - Time in seconds
        \item $C$ - Cycle duration in seconds \textit{(Configurable by ``-cd='', default $4.0$)}
        \item $t(T)$ - Normalizes time $T$ to be between 0 and 1 occilating triangularly
        \item $D_t[n]$ - Depth map vertical slice at horizonal position $t$, frequency index $n$ \textit{($0$ to $255$)}
        \item $B$ - Number of frequency bins \textit{(Configurable by ``-nb='', default $64$)}
        \item $n$ - Frequncy bin index \textit{($0$ to $B-1$)}
        \item $G_c(t)$ - Channel gain factors $t-2ct+c$
        \item $s$ - Sample index within the current audio block  \textit{($0$ to $S-1$)}
        \item $S$ - Block size in samples \textit{(Configurable by ``-bs='', default $512$)}
        \item $R$ - Sample rate in Hz \textit{(Configurable by ``-sr='', default $44100$)}
        \item $f_n$ - Frequency in Hz for bin $n$, logarithmically spaced $f_n=100\cdot \left(\frac{8000}{100}\right)^\frac{n}{B-1}$
    \end{itemize}
\item \textbf{Closed hand gesture} which is similar to open hand gesture but only translate the middle section of the depth map allowing the user to control the scanning at their own control, represented by the forumula
    \begin{equation}
    K_c(T, s) = A_\frac{1}{2}(T, c) \label{out_closed}
    \end{equation}
    Where:
    \begin{itemize}
        \item $K_c$ - Audio output for channel $c$
        \item $A_c$ - Original audio output \textit{(open hand gesture)} for channel $c$
    \end{itemize}
\item \textbf{Call me hand gesture} calls a specific user in facebook, just to test the server API and to ensure that future continuations would allow for modular or additional applications.
\end{itemize}

\subsection{System Architecture}
% Diagram the pipeline (Fig. 1: Modular components for input control, data selection, substitution).

\begin{figure}[htbp]
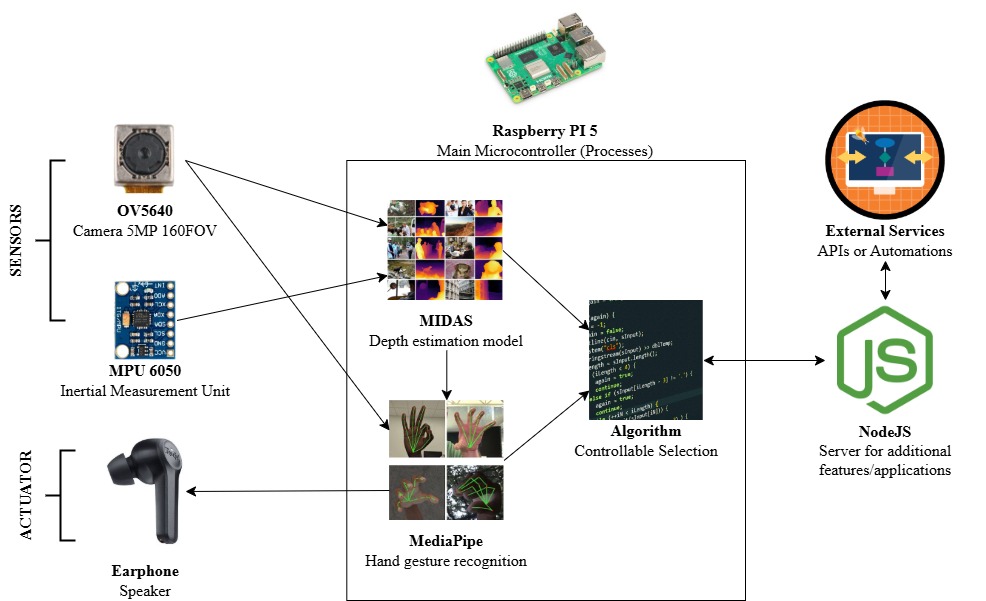
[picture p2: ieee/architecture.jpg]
    \centerline{}
    \caption{System Architecture}
    \label{architecture}
\end{figure}
The architecture in figure \ref{architecture} shows the sensors, process, and actuators of the device. For the sensors, the camera captures the image, and the IMU assist with correction and to provide the context on where the camera is capturing from. This is fed to the first process of the device which is the depth estimation model which uses the lighest MiDaS model, and is also fed to the second process of the device which is hand gesture recognition which uses MediaPipe to detect the gestures. The depth map and hand gesture are both fed into our custom algorithm that should be able to allow the user to controllably control the selection of substituted information. The algorithm also allows modular features by customizing the gesture's actions and processes, these additional processes could be sent to the server to run more computative or IoT request. The server accomplish the request by either running local processes or make additional API request to external APIs. The response of the server is recieved back by the device to the main algorithm. This algorithm then generates the nessary audio cues to be outputted by the speaker.

%\subsection{Hypothesis and Design Principles}
% Draw from psychology (selective perception); detail controllability to build subconscious patterns, reducing overload/fatigue/integration issues.

%\subsection{Implementation Details}
% Prototype specs: Hardware (e.g., camera for visual input, gesture sensors), software (e.g., algorithms for quick, silent inputs).

% ----- EXPERIMENTATION ----- %
\section{Experimental Evaluation}
% Outline tests: Metrics for overload (task accuracy), fatigue (usage duration, surveys), integration (reaction times, learning curves), device performance (control recognition accuracy). Describe setup (e.g., simulated environments, user groups), baselines from literature.
Our research conducted three seperate test to indicate if we were able to minimize the sensory limitation issue, and another test to check the device performance more specifically with hand gesture recognition, the central method of controlling the system. To test for sensory overload the users are to identify the direction of the open door to ensure they could identify near \textit{(door sides)} and far \textit{(through the door)} items. To test for sensory fatigue a survey is tested on the users during the open door identification test to check how uncomfortable they feel during long periods of using it. To test for sensory integration the user is tested how quickly they could learn to navigate with the device. Finally for hand gesture recognition, we tested multiple times if the device is able to correctly identify the gesture multiple times in different lighting conditions. All of these test are quantitative has they have clear units of measurements except for sensory fautigue testing has it is more subjective and so is qualitative.

\subsection{Experimental Setup}
% Participants (visually impaired volunteers), tools (physiological monitors, surveys), procedures (sessions with/without controllability).
There are 20 participants which are students of the University of San Agustin who are not blind, tools/materials include a room with a door to test for user's awareness, and each individual are tested in different environments at day and night, and outside and inside.

%\subsection{Evaluation Metrics}
% Quantitative: Accuracy rates, times; Qualitative: Self-reported scales (e.g., overload feedback).

% ----- RESULTS ----- %
\section{Results}
% Present data: Tables/figures showing improvements (e.g., Table I: Comparison of overload metrics vs. baselines). Avoid deep interpretation here.
\begin{figure}[htbp]
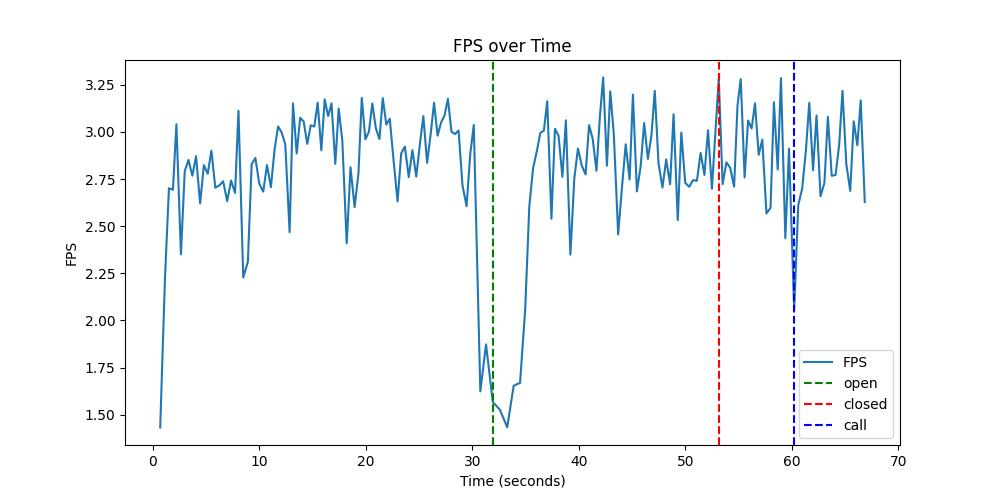
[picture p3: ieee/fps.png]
    \centerline{}
    \caption{FPS of image processing}
    \label{fps}
\end{figure}

During the testing we also analyzed the FPS during the different gesture modes to see if the FPS of guesture detection and depth map generation could hinder the user. Based on figure \ref{fps}, the FPS in the raspberry PI 5 was around 3 FPS and spikes down during gesture changes. This wont effect the audio generation has it is in a seperate thread.

\begin{table}[htbp]
    \caption{Quantity cases of door identification}
    \begin{center}
        \begin{tabular}{|c|c|c|c|}
            \hline
            Environment & Whole \textit{(open hands)} & Front \textit{(closed hands)} & Unable to \\
            \hline
            \makecell{Near the door \\ \textit{(first time)}} & 5 & 11 & 4 \\
            \hline
            \makecell{Far away \\ \textit{(first time)}} & 5 & 5 & 10 \\
            \hline
            \makecell{Near the door \\ \textit{(10 minutes }\\ \textit{learning)}} & 6 & 13 & 1 \\ 
            \hline
            \makecell{Far away \\ \textit{(10 minutes }\\ \textit{learning)}} & 8 & 5 & 7 \\
            \hline
            \multicolumn{4}{l}{$^{\mathrm{a}}$ Total 20 participants based on learning duration}
        \end{tabular}
        \label{overload}
    \end{center}
\end{table}

Table \ref{overload} shows that for people using it for the first time with a quick explaination that they have a $16/20=80\%$ accuracy when near the door \textit{(Around $1$ meter)} else $10/20=50\%$ accuracy when far to the door \textit{(Around $2$ meters)}. After they play around for 10 minutes the accuracy increases from $80\%$ to $19/20=95\%$ and from $50\%$ to $13/20=65\%$, on average a $\frac{(0.95-0.8)+(0.65-0.5)}{2}=15\%$ increase. Based on methods used show that controllability allows users to switch from whole area scanning to front area scanning based on whatever the user needs at that time showing an average increase of $\frac{\frac{13-6}{6}+\frac{11-5}{5}}{2}=118.33\%$ when switching to front scanning if near the door, while the opposite showing an average decrease of $\frac{\frac{5-5}{5}+\frac{5-8}{8}}{2}=18.75\%$. From related literatures the percentage of object recongition success is around $~54\%$ after perlong training, althrough our thesis is not about object detection rather more on data perception it does show higher average rates of recogniton being $72.5\%$, indicating lower rates but not completely ellimiated sensory overload.

\begin{table}[htbp]
    \caption{Maximum duration of users until fatigue}
    \begin{center}
        \begin{tabular}{|c|c|c|c|c|c|}
            \hline
            Situation & 30 secs & 1 min & 5 mins & 10 mins & 15+ mins \\
            \hline
            \makecell{Hearing audio \\ non-stop} & 6 & 14 & 0 & 0 & 0 \\
            \hline
            \makecell{Recovery} & 0 & 4 & 12 & 3 & 1 \\
            \hline
            \makecell{Identifying doors \\ \textit{(from last test)}} & 0 & 1 & 5 & 14 & 1 \\
            \hline
            \makecell{Navigating rooms} & 0 & 0 & 2 & 6 & 12 \\
            \hline
            \multicolumn{4}{l}{$^{\mathrm{a}}$ Total 20 participants}
        \end{tabular}
        \label{fatigue}
    \end{center}
\end{table}

Table \ref{fatigue} shows how long the user could use the device without getting fatigue \textit{(uncomfortable/annoyance/headaches)}. The first test is to see how long non-stop audio could cause fatigue, it caused on average $\frac{6\cdot 30 + 14\cdot 60}{20}=51\;seconds$ until user is fatigued. It then takes around $\frac{4\cdot 1 + 12\cdot 5 + 3\cdot 10 + 1\cdot 15}{20}=5.45\;minutes$ for a person to feel comfortable to use the device again after fatigue. In taking the previous test it took around $\frac{1\cdot 1+5\cdot 5+14\cdot 10+1\cdot 15}{20}=9.05\;minutes$ until the person gets tired in repetive testing with identifying doors. And for just navigating rooms where the person can stop any audio for a long person of time, many did not even get fautigued as they could just simply lower their hand to stop any audio, but it still took 8 participants to still get fatigued after using it for around $\frac{2\cdot 5+6\cdot 10}{8}=8.75\;minutes$, meaning the controllability really assisted in minimizing sensory fatigue.

Table \ref{overload} and \ref{fatigue} showed that users would take around $10\;minutes$ to reach the platu of sensory integration or mastery which is on average $\frac{0.95+0.65}{2}=80\%$ success in understanding the data translated to them.

\begin{table}[htbp]
    \caption{Hand gesture recognized data}
    \begin{center}
        \begin{tabular}{|c|c|c|c|c|c|}
            \hline
            Gesture & No Gesture & Open hand & Closed hand & Call \\
            \hline
            No Gesture & 30 & 0 & 0 & 0 \\
            \hline
            Open hand & 3 & 26 & 1 & 0 \\
            \hline
            Closed hand & 4 & 4 & 22 & 0 \\
            \hline
            Call & 3 & 0 & 5 & 22 \\
            \hline
            \multicolumn{4}{l}{$^{\mathrm{a}}$ Total 30 guestures tested}
        \end{tabular}
        \label{gesture}
    \end{center}
\end{table}

Table \ref{gesture} shows how accurate the hand gesture recognition is, gestures are tested alternating to ensure that there is enought time before the model predicts the next gesture and so the lightings and situation doesnt differ if they change slowly. If there is no guestures there is a $100\%$ accuracy, if the user puts an open hand it is around $\frac{26}{30}=86.67\%$ accurate, often confused on no gesture. If the user puts a closed hand it is around $\frac{22}{30}=73.33\%$ accurancy, often confused for no gesture and open hand. If the user puts a call gesture it is around $\frac{22}{30}=73.33\%$ accurate, often confused for closed hand gesture. This table shows the limitations in hand recognition probably because of the fingers being hidden in closed hand gestures, or the algorithm missing the two fingers in the call gesture. 

%\subsection{Quantitative Results}
% e.g., Reduced fatigue (longer usage before headaches), faster integration (shorter learning curves).

%\subsection{Qualitative Insights}
% User feedback on controllability ease and subconscious adaptation.

% ----- DISCUSSION ----- %
\section{Discussion}
% Interpret results: How controllability mitigates issues; limitations (e.g., assumes basic motor abilities, visual-to-audio only); scope (prototype proof-of-concept, not full product); impact (reduces inequalities per SDG 10.1–10.3, extensible to other disabilities). Suggest future work (e.g., hybrid integrations).
Based on the results it shows that we are able to minimize sensory limitation through allowing controllable selection of translated information, however among the different kinds of sensory limitation, sensory fatigue seems to be our largest issue. Its probably because sensory overload can always be minimized by chucking/breaking down information to more specific and selectable pieces of information, and learning the device can made easier by making the features more modular so that new individuals could learn and use what they need as they go, but the output is always a summation of frequencies and so even if stopped from time to time, it still causes hearing fatigue seeing how the average duration of continuous use is around $9.05$ minutes. This could be even minimized in the future by transferring some of the translated information into tactile senses, regardless we are able to show that our hypthesis has some truth to it even if it doesnt completely solve the issue of sensory limitations.

\subsection{Implications and Impact}
% Link to navigational/social equality, modular extensions for industrial applications (e.g., accessible automation tools).
The device shows that it could convey visual information into audio and that the information can be sliced/subsetted into what the user wants to hear, this has the implication of not only conveying visual information but also digital information like social media, other recognition systems like text recognition to speech, face recognition, or even object recognition allow this device to help the visually impared navigate both the physical world like physical architectures, and digital worlds like websites and platforms. The device also shows that multiple gestures could be added and when we tested the call gesture it was able to trigger the mock API to call a specific user, showing modular extensions to fit the variety needs and wants of the VIPs. Handware was not our priority rather the hypothesis, this could be implemented in existing visual device like the Meta glasses or other eyewear to make up the hardware limits and portability, such as using stereo camera and Lidar for more faster and accurate depth maps. The work could be used as a foundation to build more controllable and selective processes like implementing stero projections, point clouds, or even eye-tracking so hand gesture would not be used.

% \subsection{Limitation and Future Directions}
% Acknowledge tech's complementary role to policy/medical solutions; plans for alternative inputs (eye-tracking).

% ----- CONCLUSION ----- %
\section{Conclusion}
% Recap key findings (hypothesis validated via tests), contributions (controllable SSD prototype), and broader SDG alignment. No new info.
In conclusion, our findings shows that we were able to partially minimize the issues of sensory limitations, although less so with sensory fatigue. This study could forward the progress on the development of Sensory subsitution devices has future researchers and inventors could take inspiration from our hypothesis. By implementing these findings in more industrial technologies like eyewear, the visually impaired could possibly one day have approximately the same opportunities has the general population minimizing the navigational and societal inequalities faced by them, and by extension any disability regarding senses could be benefited from this study. 

% ----- ENDING ----- %
\section*{Acknowledgment}
% Thank advisors, funders, participants. e.g., "The authors thank [X] for support."
The authors extend their gratitude to the Office of Admissions, Scholarships and Placement, the Office of Research and Global Relations, the Vice President for Finance and Management, the Vice President for Academic Affairs, and the Office of the President at the University of San Agustin for supporting this project financially. The research team wishes to express sincere appreciation to the University of San Agustin Iloilo, especially to the College of Technology (COT), for supplying the essential resources that enabled the conduct of this study.

\begin{thebibliography}{00} % IEEE (with URL)
% 10–20 citations in IEEE style (numbered [1], [2]). Include SDG/WHO sources, SSD literature. Use BibTeX.
\bibitem{b1} P. Theodorou, K. Tsiligkos, and A. Meliones, ``Multi-sensor data fusion solutions for blind and visually impaired: Research and commercial navigation applications for indoor and outdoor spaces,'' \textit{Sensors}, vol. 23, no. 12, p. 5411, Jun. 2023, doi: 10.3390/s23125411. Available: https://doi.org/10.3390/s23125411
\bibitem{b2} World Health Organization: WHO, ``Blindness and visual impairment,'' Aug. 10, 2023. Available: https://www.who.int/news-room/fact-sheets/detail/blindness-and-visual-impairment
\bibitem{b3} Martin ``Goal 10: Reduce inequality within and among countries,'' \textit{United Nations Sustainable Development}, Nov. 25, 2025. Available: https://www.un.org/sustainabledevelopment/inequality
\bibitem{b4} Z. J. Muhsin, R. Qahwaji, F. Ghanchi, and M. Al-Taee, ``Review of substitutive assistive tools and technologies for people with visual impairments: recent advancements and prospects,'' \textit{Journal on Multimodal User Interfaces}, vol. 18, no. 1, pp. 135--156, Dec. 2023, doi: 10.1007/s12193-023-00427-4. Available: https://doi.org/10.1007/s12193-023-00427-4
\bibitem{b5} A. Arvind, ``A deep neural architecture search Net-Based wearable object classification system for the visually impaired,'' in \textit{Communications in computer and information science}, 2023, pp. 198--213. doi: 10.1007/978-3-031-46338-9\_15. Available: https://doi.org/10.1007/978-3-031-46338-9\_15
\bibitem{b6} S. Maidenbaum, S. Abboud, and A. Amedi, ``“Sensory substitution: Closing the gap between basic research and widespread practical visual rehabilitation,'' \textit{Neuroscience \& Biobehavioral Reviews}, vol. 41, pp. 3--15, Nov. 2013, doi: 10.1016/j.neubiorev.2013.11.007. Available: https://doi.org/10.1016/j.neubiorev.2013.11.007
\bibitem{b7} A. Mishra, Y. Bai, P. Narayanasamy, N. Garg, and N. Roy, ``Spatial Audio Processing with Large Language Model on Wearable Devices,'' \textit{arXiv.org}, Apr. 11, 2025. Available: https://arxiv.org/abs/2504.08907
\bibitem{b8} I. Tokmurziyev, M. A. Cabrera, M. H. Khan, Y. Mahmoud, L. Moreno, and D. Tsetserukou, ``LLM-Glasses: GenAI-driven Glasses with Haptic Feedback for Navigation of Visually Impaired People,'' \textit{arXiv.org}, Mar. 04, 2025. Available: https://arxiv.org/abs/2503.16475
\bibitem{b9} Y. Hou, Q. Xie, N. Zhang, and J. Lv, ``Cognitive load classification of mixed reality human computer interaction tasks based on multimodal sensor signals,'' \textit{Scientific Reports}, vol. 15, no. 1, p. 13732, Apr. 2025, doi: 10.1038/s41598-025-98891-3. Available: https://doi.org/10.1038/s41598-025-98891-3
\bibitem{b10} J. D. Steinmetz et al., ``Causes of blindness and vision impairment in 2020 and trends over 30 years, and prevalence of avoidable blindness in relation to VISION 2020: the Right to Sight: an analysis for the Global Burden of Disease Study,'' \textit{The Lancet Global Health}, vol. 9, no. 2, pp. e144--e160, Dec. 2020, doi: 10.1016/s2214-109x(20)30489-7. Available: https://pubmed.ncbi.nlm.nih.gov/33275949/
\bibitem{b11} United Nations, ``The Sustainable Development Goals Report 2025,''. New York, NY, USA: United Nations, 2025. Available: https://unstats.un.org/sdgs/report/2025/The-Sustainable-Development-Goals-Report-2025.pdf
\bibitem{b12} Eurostat, ``Employment gaps for women \& people with disabilities,'' \textit{Eurostat}, May 27, 2025. Available: https://ec.europa.eu/eurostat/en/web/products-eurostat-news/w/ddn-20250527-1
\bibitem{b13} V. Alcaraz-Rodríguez, D. Medina-Rebollo, A. Muñoz-Llerena, and J. Fernández-Gavira, ``Influence of Physical Activity and Sport on the Inclusion of People with Visual Impairment: A Systematic Review,'' \textit{International Journal of Environmental Research and Public Health}, vol. 19, no. 1, p. 443, Dec. 2021, doi: 10.3390/ijerph19010443. Available: https://pmc.ncbi.nlm.nih.gov/articles/PMC8744778/
\bibitem{b14} J. Shaw, M. Wickenden, S. Thompson, and P. Mader, ``Achieving disability inclusive employment -- Are the current approaches deep enough?,'' \textit{Journal of International Development}, vol. 34, no. 5, pp. 942--963, Jul. 2022, doi: 10.1002/jid.3692. Available: https://doi.org/10.1002/jid.3692
\bibitem{b15} U.S. Bureau of Labor Statistics, ``Labor force participation rate 24.2 percent for people with a disability in 2023,'' \textit{The Economics Daily}, Oct. 2024. Available: https://www.bls.gov/opub/ted/2024/labor-force-participation-rate-24-2-percent-for-people-with-a-disability-in-2023.htm
\bibitem{b16} ``Disability Employment Research: Key takeaways,'' \textit{The American Foundation for the Blind}, 2021. Available: https://afb.org/research-and-initiatives/employment/reviewing-disability-employment-research-people-blind-visually
\bibitem{b17} A. T. Parker, M. Swobodzinski, J. D. Wright, K. Hansen, B. Morton, and E. Schaller, ``Wayfinding tools for people with visual Impairments in Real-World Settings: A literature review of recent studies,'' \textit{Frontiers in Education}, vol. 6, Oct. 2021, doi: 10.3389/feduc.2021.723816. Available: https://doi.org/10.3389/feduc.2021.723816
\bibitem{b18} M. C. McDonnall and Z. Sui, ``Employment and Unemployment Rates of People Who Are Blind or Visually Impaired: Estimates from Multiple Sources,'' \textit{Journal of Visual Impairment \& Blindness}, vol. 113, no. 6, pp. 481--492, Nov. 2019, doi: 10.1177/0145482x19887620. Available: https://doi.org/10.1177/0145482x19887620
\bibitem{b19} M. M. Billah, Z. M. Yusof, K. Kadir, and A. M. M. Ali, ``Sensory substitution for Visual impairments: A Technological review,'' \textit{IntechOpen eBooks}, Dec. 2019, doi: 10.5772/intechopen.89147. Available: https://www.intechopen.com/chapters/69033
\bibitem{b20} Á. Kristjánsson et al., ``Designing sensory-substitution devices: Principles, pitfalls and potential1,'' \textit{Restorative Neurology and Neuroscience}, vol. 34, no. 5, pp. 769--787, Aug. 2016, doi: 10.3233/rnn-160647. Available: https://pmc.ncbi.nlm.nih.gov/articles/PMC5044782/
\bibitem{b21} K. C. MSEd, ``How we use selective attention to filter information and focus,'' \textit{Verywell Mind}, Dec. 18, 2023. Available: https://www.verywellmind.com/what-is-selective-attention-2795022
\bibitem{b22} T. Lloyd-Esenkaya, V. Lloyd-Esenkaya, E. O’Neill, and M. J. Proulx, ``Multisensory inclusive design with sensory substitution,'' \textit{Cognitive Research Principles and Implications}, vol. 5, no. 1, p. 37, Aug. 2020, doi: 10.1186/s41235-020-00240-7. Available: https://doi.org/10.1186/s41235-020-00240-7
\bibitem{b23} C. Jicol et al., ``Efficiency of sensory substitution devices alone and in combination with Self-Motion for spatial navigation in sighted and visually impaired,'' \textit{Frontiers in Psychology}, vol. 11, p. 1443, Jul. 2020, doi: 10.3389/fpsyg.2020.01443. Available: https://doi.org/10.3389/fpsyg.2020.01443
\bibitem{b24} J. M. Loomis, R. L. Klatzky, and N. A. Giudice, ``Sensory substitution of vision: Importance of perceptual and cognitive processing,'' in \textit{Assistive Technology for Blindness and Low Vision}, R. Manduchi and S. Kurniawan, Eds. Boca Raton, FL, USA: CRC Press, 2013, pp. 162-191. Available: https://umaine.edu/vemi/wp-content/uploads/sites/220/2016/06/Loomis-Klatzky-Giudice-in-press-sensory-substitution-chapter.pdf
\bibitem{b25} M. Sami, N. D. Agha, J. Baloch, A. Dewani, and K. D. Maheshwari, ``fficient object detection and Voice-Assisted navigation for the visually impaired: the Smart Hat approach,'' \textit{Sukkur IBA Journal of Computing and Mathematical Sciences}, vol. 8, no. 2, pp. 1--12, Feb. 2025, doi: 10.30537/sjcms.v8i2.1535. Available: https://journal.iba-suk.edu.pk:8089/SIBAJournals/index.php/sjcms/article/view/1535
\bibitem{b26} Moth, ``List of the best assistive devices for the blind,'' \textit{InviOcean}, Oct. 03, 2025. Available: https://inviocean.com/learn/best-assistive-technologies-for-visually-impared/
\bibitem{b27} E. Casanova, D. Guffanti, and L. Hidalgo, ``Technological Advancements in Human Navigation for the visually Impaired: A Systematic review,'' \textit{Sensors}, vol. 25, no. 7, p. 2213, Apr. 2025, doi: 10.3390/s25072213. Available: https://doi.org/10.3390/s25072213
\bibitem{b28} J. Krantz, ``The stimulus and anatomy of the visual system,'' \textit{Experiencing Sensation and Perception}. Harlow, England: Pearson Education Limited, 2012, ch. 3. [Online]. Available: https://psych.hanover.edu/classes/sensation/chapters/Chapter\%203.pdf
\end{thebibliography}
% ----- END ----- %
\end{document}

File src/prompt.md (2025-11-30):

I am working on my thesis that has the following summary of concept:

1. **Identifying a Problem**  
   The thesis identifies a problem aligned with global frameworks, such as the Sustainable Development Goals (SDGs), to ensure relevance and real-world impact. Specifically, it focuses on **SDG 10: Reduced Inequalities**, which targets disparities based on factors like income, age, sex, disability, race, ethnicity, origin, religion, or economic status. To narrow the scope, the work concentrates on **disability inequalities, with an emphasis on visual impairments** (e.g., blindness or low vision, affecting over 2.2 billion people per WHO estimates).

2. **Identifying the Objective**  
   Drawing from SDG 10, the primary objective is to **minimize inequalities faced by visually impaired individuals**. These fall into two major, often overlapping categories:  
   - **Navigational inequalities**: Barriers in physical and digital infrastructure not designed for accessibility (e.g., buildings without tactile guides or websites lacking audio alternatives).  
   - **Social inequalities**: Limitations in communication, societal status, or workforce participation (e.g., reduced job opportunities due to inaccessible tools or stigma in social interactions).  
   Note that inequalities are not strictly binary; for instance, job opportunities can involve both navigational challenges (e.g., vision-dependent tasks) and social ramifications (e.g., financial limitations from restricted options), aligning with SDG targets like 10.1 (reducing income inequalities through broader employment access), 10.2 (promoting social, economic, and political inclusion), and 10.3 (ensuring equal opportunities despite barriers like discrimination).

3. **Identifying a Solution**  
   Approaches to addressing these inequalities are not mutually exclusive and can blend elements, though they often prioritize one aspect:  
   - **Assistive technologies**, which primarily extend existing capabilities (e.g., canes, guide dogs, or braille displays).  
   - **Substitution technologies**, which primarily represent missing senses through alternatives (e.g., screen readers or sensory substitution devices that convert visual data to audio/tactile feedback).  
   The thesis prioritizes the **substitution approach** due to its potential for comprehensive impact on the identified objectives, enabling more independent navigation and interaction, while acknowledging that hybrid solutions may incorporate assistive elements.

4. **Identifying the Issues**  
   Substitution technologies, particularly sensory substitution devices (SSDs), encounter significant, interconnected challenges generalized as **sensory limitations**:  
   - **Sensory overload**: When translated information exceeds the brain's processing capacity.  
   - **Sensory fatigue**: Prolonged use leading to mental exhaustion.  
   - **Sensory integration**: Difficulty in learning or subconsciously interpreting the substituted signals.  
   These stem from the core limitation of representing one sense through another and must be addressed for effective adoption.

5. **Identifying our Hypothesis**  
   Inspired by human psychology—where perception is **selective rather than raw data intake**—the hypothesis posits that SSDs can minimize sensory limitations by making the process **controllable**. This allows the brain to build subconscious patterns efficiently. For the prototype, users could control the "focus" of emulated vision via **silent, quick inputs like hand gestures**, mimicking eye muscle adjustments. However, the core focus is on controllability itself, with the method being modular (e.g., adaptable to voice, head tilts, or eye-tracking for users with varying abilities) to suit the hypothesis without restricting to one input type.

6. **Identifying the Tests**  
   To validate the hypothesis, evaluate the device's efficiency in mitigating sensory limitations through a mix of quantitative and qualitative metrics:  
   - **Sensory overload**: Measure user accuracy in interpreting generated audio cues (e.g., via task completion rates) and qualitative feedback on perceived overload.  
   - **Sensory fatigue**: Assess usage duration before symptoms like headaches emerge (e.g., via self-reported scales, physiological monitoring, or user surveys).  
   - **Sensory integration**: Track reaction times to environmental data, learning curves over sessions, and survey responses on ease of subconscious adaptation.  
   - **Device performance**: Test accuracy in recognizing user controls (e.g., hand gestures) and generating relevant audio from environmental inputs.  
   Evaluations will include comparisons to baselines from related literature on existing SSDs, incorporating user-centered qualitative insights (e.g., surveys) to account for individual experiences.

7. **Identifying the Impact**  
   If successful, the device could substitute visual information as audio via a **modular pipeline**, enabling extensions for diverse needs (e.g., customizable adaptations for varying lifestyles or impairment levels). This would reduce navigational inequalities (e.g., accessible OS and environments for better job opportunities) and social inequalities (e.g., enhanced communication tools), contributing to SDG 10 targets such as 10.1 (income growth via expanded employment), 10.2 (empowerment through regained navigational and social inclusion), and 10.3 (equal opportunities in workforce and society). While not resolving all issues (e.g., medical treatments or systemic discrimination), it demonstrates the possibility of partially minimizing sensory limitations—evidenced by test results showing users can interpret data with reduced overload, fatigue, or integration challenges—paving the way for applications to other sensory disabilities.

8. **Identifying the Scope and Limitations**  
   The thesis prioritizes proving the hypothesis—that sensory limitations can be partially addressed through selective, controllable substitution—rather than perfecting the device or developing all extensions. By completion, the output will be a prototype SSD that emulates visual perception as audio, minimizes limitations, and features a modular pipeline for future enhancements (e.g., alternative controls). Limitations include assumptions of basic user abilities for prototype inputs, focus on visual-to-audio substitution only, and recognition that tech complements broader efforts like policy changes for full inequality reduction.

I plan to accomplish this device by running the program which is a python file on the raspberry pi 5 which uses the two cameras (both 5mp at 160fov) connected to it through USB, it is also connected to a MPU-9250, and earphones. All of this is fitted into a hat so that the cameras would capture the image directly infront of the user and even till their foot so that they wont trip on objects and so the device could capture the hand gesture. So the main process is as such:

1. **Depth Map Generation**
   The program will use the two cameras apply stereo vision (opencv), to generate the depth map. *(The MPU can be used to ensure the generate map is accurate, maybe not needed)*. Allow a mode/flag to switch to MiDaS_small instead of using stereo vision
2. **Hand Gesture Recogntion**
   The program will detect the right hand of the user in the right camera, and the hand gesture can determine the final output
3. **Emulated Human Vision**
   The audio output is determined by the following gestures:
   1. **No Hand Gesture** - No sound, the device will not generate any audio output
   2. **Backhand from Open to Close** - If the backhand is visible then the audio output will be of depth, a variable called *radius* is based on the closeness of the hand like a completely open hand would be *radius* of 1 where the whole depth map is translated to audio but at a cost of details, and a completely closed hand would be *radius* of 0 where only the center of the depth map is translated. *(Note that the radius of 1 might still be too overloading thus there should be an option to play the audio from right to left based on a variable called echo? where 0 seconds means echo is off and any other time means it takes that time to play from right to left, or negative from left to right)*
   3. **Any other Gesture** - No sound
4. **Audio Generation**
   The standard for audio generation is has follows:
   1. **Channels** - the position of the depth(left/right of the image) is positioned into the left/right channels of the audio
   2. **Volume** - the depth of the point is represented has the volume, so louder means closer and at a specific treshold there is no volume
   3. **Frequency** - the vertical placement is represented as frequency where higher frequency means the thing is higher/above, since frequency of the same volume can sound different the Equal loudness contours is taken into account in modifying the final frequency output

**Syntax**
```sh
./thesis.py [flags]
```

**Primary Flags**
- `-h` - Help menu, displays all available flags to use and their default value
- `-gw` - Enables graphical
- `-co` - Calibration output, enables calibration mode
- much more

**Incomplete python code**
Please keep syntax and coding style like minimizing function so its easier to make flowcharts and use regions so that I dont need to seperate the code into multiple files
```py
#!/usr/bin/env -S python
#region - Setup
#region -- Intialization
#region --- Needed packages
import cv2                                                                  # OpenCV - Image generation
import numpy as np                                                          # Numpy - Data processing
import threading                                                            # Threading - For multi-threading
import queue                                                                # Queue - For safe multi-threading
from typing import cast, List, Optional, Dict, Any                          # Typing
from numpy.typing import NDArray                                            # - Numpy Array type
import json                                                                 # JSON - For calibration data
import os                                                                   # OS - For file system
#endregion
#region --- Argument parsing
import sys                                                                  # System - For CLI arguments
from typing import TypeVar, Callable
T = TypeVar('T')
def arg(deff:T, pref:str, run:Callable[[str],T]=lambda x:x) -> T:
    return [*[run(arg[len(pref):]) for arg in sys.argv if arg.startswith(pref)],deff][0]
#endregion
#endregion
#region -- Calibration
chessboard:tuple[int,int]   = arg([9,6],'-bd=', lambda t:[int(v) for v in t.split('x')])
square_size:float           = arg(20.0, '-sq=', float)
camera_id:tuple[int,int]    = arg([0,2],'-ci=', lambda t:[int(v) for v in t.split(',')])
img_scale:float             = arg(0.5,  '-sc=', float)
calibration_out:str         = arg('',   '-co=')
baseline_cm:float           = arg(14.5, '-bl=', float)
calib_imgs:tuple[List[NDArray],List[NDArray]] = [[],[]]
calib_data:Optional[Dict[str,Any]] = None
calib_results:List[Dict[str,Any]] = []
selected_test:int           = -1
#endregion
#region -- Hand Gesture Recognition
hand_gesture:bool           = arg('f',  '-hg') == ('' if len(calibration_out) else 'f')
if hand_gesture:
    import mediapipe as mp
    from mediapipe.python.solutions import hands as mp_hands                    # MediaPipe Hands
    from mediapipe.python.solutions import drawing_utils as mp_drawing          # MediaPipe Rendering Hand Points
    from mediapipe.python.solutions import drawing_styles as mp_drawing_styles  # MediaPipe Rendering Hand Points
    hands = mp_hands.Hands(
        static_image_mode=False,
        max_num_hands=1,
        min_detection_confidence=0.5,
        min_tracking_confidence=0.5
    )
#endregion
#region -- Audio Generation
import sounddevice as sd                                                    # SoundDevice - For audio output
import time                                                                 # Time - For period/time
sample_rate:int             = arg(44100,'-sr=', int)
block_size:int              = arg(512,  '-bs=', int)
num_bins:int                = arg(64,   '-nb=', int)
history_duration:float      = arg(10.0, '-hd=', int)
time_counter:tuple[float]   = [0]
time_start:float            = time.time()
frequencies = np.logspace(np.log10(100), np.log10(8000), num_bins)
time_block = np.arange(block_size) / sample_rate
audio_enabled:bool          = arg('f',  '-ae') == ''
#endregion
#region -- Graphical window
import matplotlib.pyplot as plt                                             # Matplotlib - Rendering graphs
gui_window:bool             = arg('f',  '-gw') == '' or len(calibration_out)
#endregion
#endregion

#region - Functions
#region -- Logging
EXIT = 1
SUCCESS = 2
WARNING = 4
ERROR = 6
def log(code:int, msg:str) -> None:
    print(['\x1b[1;2mLog','\x1b[1;32mSuccess','\x1b[1;33mWarning','\x1b[1;31mError'][code>>1]+':\x1b[0m '+msg)
    if code&1:
        print('\x1b[2m----- EXITED -----\x1b[0m')
        exit()
#endregion
#region -- Calibration File Management
def load_calibration() -> bool:
    global calib_data, calib_results, selected_test
    if not calibration_out or not os.path.exists(f"{calibration_out}.json"):
        return False
    
    try:
        with open(f"{calibration_out}.json", 'r') as f:
            data = json.load(f)
        
        calib_results = data.get('tests', [])
        if not calib_results:
            return False
        
        selected_test = len(calib_results) - 1
        test_data = calib_results[selected_test]
        
        # Convert lists back to numpy arrays with correct dtypes
        for key in ['camera_matrix_left', 'dist_coeffs_left', 'camera_matrix_right', 
                    'dist_coeffs_right', 'R', 'T', 'E', 'F', 'R1', 'R2', 'P1', 'P2', 'Q']:
            if key in test_data:
                test_data[key] = np.array(test_data[key])
        
        # Rectification maps need specific dtypes
        if 'map1_left' in test_data:
            test_data['map1_left'] = np.array(test_data['map1_left'], dtype=np.int16)
        if 'map2_left' in test_data:
            test_data['map2_left'] = np.array(test_data['map2_left'], dtype=np.uint16)
        if 'map1_right' in test_data:
            test_data['map1_right'] = np.array(test_data['map1_right'], dtype=np.int16)
        if 'map2_right' in test_data:
            test_data['map2_right'] = np.array(test_data['map2_right'], dtype=np.uint16)
        
        calib_data = test_data
        log(SUCCESS, f"Loaded {len(calib_results)} calibration test(s)")
        return True
    except Exception as e:
        log(ERROR, f"Failed to load calibration: {str(e)}")
        return False

def save_calibration(new_calib_data: Dict[str,Any]) -> None:
    global calib_data, calib_results, selected_test
    try:
        # Convert numpy arrays to lists for JSON serialization
        save_data = {}
        for key, value in new_calib_data.items():
            if isinstance(value, np.ndarray):
                save_data[key] = value.tolist()
            else:
                save_data[key] = value
        
        calib_results.append(save_data)
        selected_test = len(calib_results) - 1
        
        # Save to file
        with open(f"{calibration_out}.json", 'w') as f:
            json.dump({'tests': calib_results}, f, indent=2)
        
        # Restore numpy arrays for current use
        for key in ['camera_matrix_left', 'dist_coeffs_left', 'camera_matrix_right', 
                    'dist_coeffs_right', 'R', 'T', 'E', 'F', 'R1', 'R2', 'P1', 'P2', 'Q',
                    'map1_left', 'map2_left', 'map1_right', 'map2_right']:
            if key in new_calib_data:
                new_calib_data[key] = np.array(new_calib_data[key])
        
        calib_data = new_calib_data
        log(SUCCESS, f"Saved calibration test {selected_test+1}")
    except Exception as e:
        log(ERROR, f"Failed to save calibration: {str(e)}")
#endregion
#region -- Stereo Calibration
def run_stereo_calibration(frames_left: List[NDArray], frames_right: List[NDArray], 
                          img_shape: tuple[int, int]) -> Optional[Dict[str,Any]]:
    if len(frames_left) < 5:
        log(WARNING, "Need at least 5 calibration images")
        return None
    
    log(0, "Processing calibration images...")
    
    # Prepare object points
    objp = np.zeros((chessboard[0] * chessboard[1], 3), np.float32)
    objp[:, :2] = np.mgrid[0:chessboard[0], 0:chessboard[1]].T.reshape(-1, 2)
    objp *= (square_size / 1000.0)  # Convert to meters
    
    obj_points: List[NDArray] = []
    img_points_left: List[NDArray] = []
    img_points_right: List[NDArray] = []
    
    # Find chessboard corners in all frames
    for i, (frame_l, frame_r) in enumerate(zip(frames_left, frames_right)):
        gray_l = cv2.cvtColor(frame_l, cv2.COLOR_BGR2GRAY)
        gray_r = cv2.cvtColor(frame_r, cv2.COLOR_BGR2GRAY)
        
        ret_l, corners_l = cv2.findChessboardCorners(gray_l, chessboard, None)
        ret_r, corners_r = cv2.findChessboardCorners(gray_r, chessboard, None)
        
        if ret_l and ret_r:
            criteria = (cv2.TERM_CRITERIA_EPS + cv2.TERM_CRITERIA_MAX_ITER, 30, 0.001)
            corners_l = cv2.cornerSubPix(gray_l, corners_l, (11, 11), (-1, -1), criteria)
            corners_r = cv2.cornerSubPix(gray_r, corners_r, (11, 11), (-1, -1), criteria)
            
            obj_points.append(objp)
            img_points_left.append(corners_l)
            img_points_right.append(corners_r)
    
    if len(obj_points) < 5:
        log(WARNING, "Not enough valid calibration images")
        return None
    
    log(0, f"Calibrating with {len(obj_points)} valid image pairs...")
    
    # Calibrate individual cameras
    ret_l, mtx_l, dist_l, _, _ = cv2.calibrateCamera(
        obj_points, img_points_left, img_shape, None, None)
    
    ret_r, mtx_r, dist_r, _, _ = cv2.calibrateCamera(
        obj_points, img_points_right, img_shape, None, None)
    
    # Stereo calibration
    flags = cv2.CALIB_FIX_INTRINSIC
    criteria = (cv2.TERM_CRITERIA_EPS + cv2.TERM_CRITERIA_MAX_ITER, 100, 1e-5)
    
    ret, mtx_l, dist_l, mtx_r, dist_r, R, T, E, F = cv2.stereoCalibrate(
        obj_points, img_points_left, img_points_right,
        mtx_l, dist_l, mtx_r, dist_r,
        img_shape, criteria=criteria, flags=flags)
    
    # Stereo rectification
    R1, R2, P1, P2, Q, _, _ = cv2.stereoRectify(
        mtx_l, dist_l, mtx_r, dist_r,
        img_shape, R, T, alpha=0)
    
    # Compute rectification maps
    map1_left, map2_left = cv2.initUndistortRectifyMap(
        mtx_l, dist_l, R1, P1, img_shape, cv2.CV_16SC2)
    
    map1_right, map2_right = cv2.initUndistortRectifyMap(
        mtx_r, dist_r, R2, P2, img_shape, cv2.CV_16SC2)
    
    calculated_baseline = np.linalg.norm(T) * 100  # Convert to cm
    
    return {
        'camera_matrix_left': mtx_l,
        'dist_coeffs_left': dist_l,
        'camera_matrix_right': mtx_r,
        'dist_coeffs_right': dist_r,
        'R': R,
        'T': T,
        'E': E,
        'F': F,
        'R1': R1,
        'R2': R2,
        'P1': P1,
        'P2': P2,
        'Q': Q,
        'map1_left': map1_left,
        'map2_left': map2_left,
        'map1_right': map1_right,
        'map2_right': map2_right,
        'reprojection_error': ret,
        'baseline_cm': baseline_cm,
        'calculated_baseline_cm': calculated_baseline,
        'valid_points': len(obj_points[0]) * len(obj_points),
        'image_shape': img_shape
    }

def compute_depth_map(frame_left: NDArray, frame_right: NDArray) -> NDArray:
    if calib_data is None:
        return np.zeros((height, width, 3), dtype=np.uint8)
    
    # Rectify images
    rect_left = cv2.remap(frame_left, calib_data['map1_left'], 
                         calib_data['map2_left'], cv2.INTER_LINEAR)
    rect_right = cv2.remap(frame_right, calib_data['map1_right'], 
                          calib_data['map2_right'], cv2.INTER_LINEAR)
    
    # Convert to grayscale
    gray_left = cv2.cvtColor(rect_left, cv2.COLOR_BGR2GRAY)
    gray_right = cv2.cvtColor(rect_right, cv2.COLOR_BGR2GRAY)
    
    # Create stereo matcher
    stereo = cv2.StereoBM_create(numDisparities=16*10, blockSize=15)
    
    # Compute disparity
    disparity = stereo.compute(gray_left, gray_right).astype(np.float32) / 16.0
    
    # Normalize and colorize
    disparity_normalized = cv2.normalize(disparity, None, 0, 255, cv2.NORM_MINMAX)
    depth_colored = cv2.applyColorMap(disparity_normalized.astype(np.uint8), 
                                     cv2.COLORMAP_JET)
    return depth_colored
#endregion
#region -- Capturing camera
frame_queues = [queue.Queue(maxsize=1) for _ in range(2)]
stop_event = threading.Event()
def capture_thread(cam_idx, cam):
    while not stop_event.is_set():
        cam.grab()
        ret, frame = cam.retrieve()
        if ret:
            if img_scale != 1.0:
                frame = cv2.resize(frame, (width, height))
            try:
                frame_queues[cam_idx].put_nowait(frame)
            except queue.Full:
                pass
#endregion
#region -- Audio Generation
phases = [np.zeros(num_bins) for _ in range(2)]
t_buff = np.arange(block_size) / sample_rate
def audio_callback(outdata, frames, time_info, status):
    if status: print(f"Status: {status}")
    time_counter[0] += 0.01
    audio = [np.zeros(block_size) for _ in range(2)]
    
    # Peak computation (temporary)
    peak_pos = (np.sin(time_counter[0]*2)+1)/2
    vars = [0.1*np.exp(-((np.arange(num_bins) - (n+(1-2*n)*peak_pos) * num_bins) ** 2) / 20) for n in range(2)]
    
    for i, freq in enumerate(frequencies):
        phase_increment = 2 * np.pi * freq * t_buff
        for n in range(2):
            audio[n] += vars[n][i] * np.sin(phase_increment + phases[n][i])
            phases[n][i] = (phases[n][i] + 2*np.pi*freq*block_size/sample_rate) % (2*np.pi)
    
    # Normalize
    max_val = max(np.abs(aud).max() for aud in audio)
    if max_val > 0: audio = [aud/max_val for aud in audio]
    
    outdata[:] = np.column_stack(audio).astype(np.float32)[:frames]
#endregion
#endregion

#region - Initalizating
#region -- Connecting to cameras
log(0, 'Connecting to cameras')
cameras = [cv2.VideoCapture(n) for n in camera_id]
if err:=sum((not cam.isOpened())<<n for n, cam in enumerate(cameras)):
    log(ERROR|EXIT, f"Could not open {['','left','right','both'][err]} camera/s")
log(0, 'Eliminating camera buffer')
for camera in cameras: camera.set(cv2.CAP_PROP_BUFFERSIZE, 1)
#endregion
#region -- Checking camera dimensions
log(0, 'Getting camera dimensions')
init_frames = cast(tuple[tuple[bool,NDArray[np.uint8]],tuple[bool,NDArray[np.uint8]]], [camera.read() for camera in cameras])
if err:=sum((not res[0])<<n for n, res in enumerate(init_frames)):
    log(ERROR|EXIT, f"Could not read {['','left','right','both'][err]} camera/s")
if err:=sum((init_frames[0][1].shape[:2][n] != init_frames[1][1].shape[:2][n])<<n for n in range(2)):
    log(ERROR|EXIT, f"Camera {['','width', 'height', 'dimension']} does't match")
height, width = [int(dim*img_scale) for dim in init_frames[0][1].shape[:2]]
#endregion
#region -- Load existing calibration
if calibration_out:
    load_calibration()
#endregion
#region -- Start audio
if audio_enabled:
    audio_stream = sd.OutputStream(
        samplerate=sample_rate,
        blocksize=block_size,
        channels=2,
        callback=audio_callback,
        dtype=np.float32
    )
    audio_stream.start()
#endregion
#region -- Window
if gui_window:
    #region --- Window Intialization
    from matplotlib.gridspec import GridSpec
    from matplotlib.animation import FuncAnimation
    log(0, 'Creating graphical window')

    plt.ion()
    fig = plt.figure(figsize=(16,9), num='Thesis')
    gs = GridSpec(2, 2, height_ratios=[3, 1], hspace=0.15, wspace=0.15)
    
    # First Row - Cameras
    placeholder = np.zeros((height, width, 3), dtype=np.uint8)
    camera_axs = [fig.add_subplot(gs[0, n]) for n in range(2)]
    camera_imgs = [camera_axs[n].imshow(placeholder) for n in range(2)]
    for ax in camera_axs:
        ax.set_aspect('equal')
        ax.autoscale(enable=True, axis='both', tight=True)
        ax.axis('off')
    camera_axs[0].set_title('Left Camera')
    camera_axs[1].set_title('Right Camera')
    
    # Second Row - Calibration/Depth
    brow = [fig.add_subplot(gs[1, n]) for n in range(2)]
    if len(calibration_out):
        brow[0].set_title(f'Calibration Error')
        brow[0].set_xlabel('Test Number', fontsize=10)
        brow[0].set_ylabel('Reprojection Error (px)', fontsize=10)
        
        brow[1].set_title('Depth Map')
        brow[1].axis('off')
        depth_img = brow[1].imshow(placeholder)
    else:
        brow[0].set_title('Left Audio Channel')
        brow[0].set_xlabel('Time (seconds)', fontsize=10)
        brow[0].set_ylabel('Frequency (Hz)', fontsize=10)
        brow[1].set_title('Right Audio Channel')
        brow[1].set_xlabel('Time (seconds)', fontsize=10)
        brow[1].set_ylabel('Frequency (Hz)', fontsize=10)
    
    fig.suptitle('Thesis Calibration' if len(calibration_out) else 'Thesis Demo', fontsize=16)
    
    # Start capture threads
    threads = [threading.Thread(target=capture_thread, args=(i, cam), daemon=True) for i, cam in enumerate(cameras)]
    for t in threads: t.start()
    
    # Keyboard state
    key_pressed = [None]
    def on_key(event):
        key_pressed[0] = event.key
    fig.canvas.mpl_connect('key_press_event', on_key)
    
    log(0, 'Starting main loop')
    #endregion
    #region --- Main loop thread
    def update_animation(frame_num):
        #region ---- Capturing camera
        cam_frames = [None] * 2
        for i in range(2):
            try:
                cam_frames[i] = frame_queues[i].get_nowait()
            except queue.Empty:
                pass
        
        err = sum((cam_frames[n] is None)<<n for n in range(2))
        if err:
            log(WARNING,f"Failed to capture image from {['','left','right','both'][err]} camera/s")
        #endregion
        #region ---- Hand gesture recognition
        if hand_gesture and not err:
            frame_rgb = cv2.cvtColor(cam_frames[1], cv2.COLOR_BGR2GRAY)
            frame_rgb = cv2.cvtColor(frame_rgb, cv2.COLOR_GRAY2RGB)
            results = hands.process(frame_rgb)
            
            if results.multi_hand_landmarks and results.multi_handedness:
                for hand_landmarks, handedness in zip(results.multi_hand_landmarks, results.multi_handedness):
                    mp_drawing.draw_landmarks(
                        frame_rgb,
                        hand_landmarks,
                        cast(List[tuple[int, int]], mp_hands.HAND_CONNECTIONS),
                        mp_drawing_styles.get_default_hand_landmarks_style(),
                        mp_drawing_styles.get_default_hand_connections_style()
                    )
            cam_frames[1] = cv2.cvtColor(frame_rgb, cv2.COLOR_RGB2BGR)
        #endregion
        #region ---- Calibration training
        if len(calibration_out) and not err:
            #region ----- Handle keyboard input
            key = key_pressed[0]
            key_pressed[0] = None
            
            if key == ' ':  # SPACE - Capture calibration
                gray_l = cv2.cvtColor(cam_frames[0], cv2.COLOR_BGR2GRAY)
                gray_r = cv2.cvtColor(cam_frames[1], cv2.COLOR_BGR2GRAY)
                
                ret_l, _ = cv2.findChessboardCorners(gray_l, chessboard, None)
                ret_r, _ = cv2.findChessboardCorners(gray_r, chessboard, None)
                
                if ret_l and ret_r:
                    calib_imgs[0].append(cam_frames[0].copy())
                    calib_imgs[1].append(cam_frames[1].copy())
                    
                    # Save images
                    test_num = len(calib_results) + 1
                    img_num = len(calib_imgs[0])
                    os.makedirs(f"{calibration_out}/{test_num}", exist_ok=True)
                    cv2.imwrite(f"{calibration_out}/{test_num}/L{img_num}.png", cam_frames[0])
                    cv2.imwrite(f"{calibration_out}/{test_num}/R{img_num}.png", cam_frames[1])
                    
                    log(SUCCESS, f"Captured frame {img_num}")
                else:
                    log(WARNING, "Pattern not detected in both cameras")
            
            elif key == 'enter' and len(calib_imgs[0]) > 0:  # ENTER - Process calibration
                log(0, "Processing calibration...")
                result = run_stereo_calibration(calib_imgs[0], calib_imgs[1], (width, height))
                
                if result is not None:
                    save_calibration(result)
                    calib_imgs[0].clear()
                    calib_imgs[1].clear()
                    
                    # Update graph
                    if len(calib_results) > 0:
                        brow[0].clear()
                        brow[0].set_title(f'Calibration Error')
                        brow[0].set_xlabel('Test Number', fontsize=10)
                        brow[0].set_ylabel('Reprojection Error (px)', fontsize=10)
                        
                        errors = [r['reprojection_error'] for r in calib_results]
                        brow[0].plot(range(1, len(errors)+1), errors, 'bo-', linewidth=2, markersize=8)
                        brow[0].grid(True, alpha=0.3)
            #endregion
            #region ----- Chessboard detection and display
            rets = [False, False]
            corners = [None, None]
            
            for n in range(2):
                gray = cv2.cvtColor(cam_frames[n], cv2.COLOR_BGR2GRAY)
                ret, corner = cv2.findChessboardCorners(gray, chessboard, None)
                rets[n] = ret
                corners[n] = corner
                
                if ret:
                    cv2.drawChessboardCorners(cam_frames[n], chessboard, corner, ret)

            status = "READY" if all(rets) else "NO PATTERN"
            color = (0, 255, 0) if all(rets) else (0, 0, 255)

            for n in range(2):
                cv2.putText(cam_frames[0], f"CALIBRATION: {status}", (10, 30), cv2.FONT_HERSHEY_SIMPLEX, 0.5, color if n else (0,0,0), 3-n)
                cv2.putText(cam_frames[0], f"Captured: {len(calib_imgs[0])}", (10, 60), cv2.FONT_HERSHEY_SIMPLEX, 0.5, (255*n,)*3, 3-n)
                cv2.putText(cam_frames[0], "SPACE=Capture, ENTER=Process", (10, 90), cv2.FONT_HERSHEY_SIMPLEX, 0.5, (255*n,)*3, 3-n)
            #endregion
            #region ----- Update depth map if calibration exists
            if calib_data is not None:
                depth_map = compute_depth_map(cam_frames[0], cam_frames[1])
                depth_img.set_data(cv2.cvtColor(depth_map, cv2.COLOR_BGR2RGB))
            #endregion
        #endregion
        #region ---- Output
        for i in range(2):
            if cam_frames[i] is not None:
                rgb_frame = cv2.cvtColor(cam_frames[i], cv2.COLOR_BGR2RGB)
                camera_imgs[i].set_data(rgb_frame)
        
        return_list = camera_imgs.copy()
        if len(calibration_out) and calib_data is not None:
            return_list.append(depth_img)
        return return_list
        #endregion
    #endregion
    #region --- Ending
    ani = FuncAnimation(fig, update_animation, interval=10, blit=True, cache_frame_data=False)
    plt.show(block=True)
    
    # Cleanup
    stop_event.set()
    for t in threads: t.join()
    for q in frame_queues: q.queue.clear()
    #endregion
#endregion
#endregion
```

Please generate the whole complete code for this project

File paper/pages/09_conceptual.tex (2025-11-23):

% Conceptual Framework
\subsection{Conceptual Framework}

\begin{figure}[H]
    \centering
    \caption{IPO Model of the Conceptual Frame of the Study}
    \begin{plantuml}
        @startuml
        skinparam rectangle {
            BackgroundColor WhiteSmoke
            BorderColor Black
        }
        skinparam linetype ortho

        rectangle "<size:14><b>INPUT</b></size>\n\n<b>Hardware:</b>\n• Orange PI 2W\n• 5V/3A UPS module\n• OV5640 Camera\n• Binaural Earphone\n• SIM868 with GPS\n• MPU 6050\n\n<b>Software:</b>\n• GitHub\n• Microsoft Word\n• Linux\n• DenoJS\n• VSCode\n\n<b>Wireless Connectivity:</b>\n• 2/3G or Wi-Fi" as input #WhiteSmoke

        rectangle "<size:14><b>PROCESS</b></size>\n\n\n\n\n1. Problem Statement\n2. Literature Review\n   (RRL)\n3. Prototyping\n   1. Requirements\n   2. Designing\n   3. Gathering materials\n4. Development\n   5. Refinement\n   6. Implementation\n   7. Testing\n   8. Analysing\n\n\n" as process #WhiteSmoke

        rectangle "<size:14><b>OUTPUT</b></size>\n\n\n\n\nDevelopment of\nWearable Navigation Aid\nusing AIoT for the\nVisually Impaired\n\n\n\n\n\n\n\n\n\n" as output #WhiteSmoke

        rectangle "<size:14><b>FEEDBACK</b></size>" as feedback #WhiteSmoke

        input -right-> process
        process -right-> output
        output -down-> feedback
        feedback -left-> input
        @enduml
    \end{plantuml}
    \label{fig:ipo}
\end{figure}

%Figure \ref{fig:ipo} states the conceptual framework of our research in a form of an Input-Process-Output (IPO) model. We start with three kinds of required input such has Hardware for our Microcontroller, Sensors, Actuators, and SIM Module, Software for our Project management, Client-side device, and Server-side device, and the Wireless Connectivity used in our device which can be either 2/3G which is used on deployment doors, or Wi-Fi which is used deployment indoors or development. Our method of research mimics typical development cycle with addition to literature review and research, such has literature review, prototyping, designing, etc. By the end of each iterative development we are to expect to be closer to the end goal, with a feedback from either advisor or mentor to start the cycle again until our end goal of an wearable navigation aid is developed.

\todo{Explain Futher}
Figure \ref{fig:ipo} states the conceptual framework of the research in the form of an Input-Process-Output (IPO) model. Starting with three kinds of required input such as the hardware components Microcontroller, Sensors, Actuators, and SIM Module, as the Software for Project management, Client-side device, and Server-side device, and the Wireless Connectivity used on to the device which can be either 2/3G used for deployment doors, or Wi-Fi as used in deployment indoors or development. The method of the research mimics typical development cycles with addition to literature review and research, such as literature review, prototyping, designing, testing/evaluating, and implementation. By the end of each iterative development the researchers expects to be closer to the end goal, with feedback from users and professionals to start the cycle again until the end goal of a wearable navigation aid is developed.

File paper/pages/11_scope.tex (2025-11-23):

% Scope and Delimitaton
\clearpage
\subsection{Scope and Delimitation}

The research focuses on Sensory Substitution Devices, more specifically on Vision Substitution. Our device aims to fill in what different variety of visually impaired individuals lacks, like if fully blind our device should be able to act as an artificial eye providing information the person wants, or if the person is near sighted it could read text from afar from the user and warn of objects rapidly approaching the user, and so on. It does this by having a modular system running the main pipeline, the main pipeline inputs images from the stereo camera, creates a point cloud, maps it to a virtual physical map, follows an algorithm to emulate human vision processes, and finally generate the necessary audio cues for the individual. This pipeline allows applications to take into account more varied needs such has hand gesture recognition to control the parameters of the main pipeline so the person can navigate the device without seeing anything, image recognition to read text near or far, face recognition to recognize friends and family, and even more personalized interest like keeping track of expenses.

%This research is conducted in the University of San Agustin and thus the prototype is initially to be tested by the researchers who only half of them are little bit near sighted, our testing sample is to soon include members of Iloilo blind associations such as the Association of Disabled Persons - Iloilo Inc. The main pipeline is prioritized over other features has it is the central component and partially answers the research question of solving existing sensory substitution issues. Has a result our prototype doesn't take into much consideration the much varied range of visual imparities, and since our study prioritize the main function over the physical design, the prototype would be heavier than what it could be if optimized for weight. However, our main objective is to build the main pipeline and the capability of support applications anywhere in the pipeline (modular operating system) showing it is possible that some of the issues facing most sensory substitution devices could be solved.

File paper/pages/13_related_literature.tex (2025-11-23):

\subsection{Review of Related Literature}

\textcite{zvori_teanu_2021} presented the Sound of Vision (SoV) system. It is a wearable SSD designed to aid VIPs in spatial cognition and navigation, using stereo-vision-based 3D reconstruction to interpret the environment and translate spatial data into audio and haptic cues. The device integrates a stereo camera, an infrared depth sensor, and an inertial measurement unit (IMU) to track the motion of the user’s head and the installed camera mounted on the headgear, using these as its inputs. Furthermore, the output audio and haptic feedback are delivered via headphones and a haptic belt. The device processes visual data in real time using GPU-accelerated computation to reconstruct the 3D Environment and identify obstacles via segmentation algorithms based on disparity and histogram analysis. The depth of each pixel is determined by the stereo disparity formula $Z=\frac{f\cdot B}{d}$, where $Z$ is the depth, $B$ is the baseline, $f$ is the focal length, and $d$ is the disparity. The SoV converts environmental data into audio-haptic cues, allowing users to detect obstacles, open spaces, and open areas. In testing the device's performance with the visually impaired participants, it showed a $10\%$ improvement in depth accuracy and an $88.5\%$ task success rate compared to standard stereo vision methods. The results highlight the device's effectiveness in real-world navigation and its potential to enhance mobility and spatial awareness compared to traditional aids such as white canes.

\textcite{sami_2025} developed a smart wearable (hat) assistive device that integrates object detection with voice-assisted navigation to support VIP in real-time spatial awareness. The device uses an ESP32-CAM module to capture live video and transmit it via Wi-FI to a mobile application that employs a TensorFlow-based deep learning model for efficient object recognition. The camera-detected objects are then processed into audio prompts that send alerts to the user when there are nearby obstacles and provide navigation directions. The programmed system produced a seamless object-detection-to-voice pipeline. The Smart Hat's system architecture demonstrates the integration of an IoT processing method to enable wireless communication between the smart hat and the user interface for remote processing and real-time updates for the user. Testing results show an object detection accuracy of over $91\%$, highlighting the reliability in dynamic environments. In addition, the Smart Hat device offers compact, low-cost, and user-friendly features. It demonstrates how IoT-enabled computer vision can transform traditional assistive technologies into intelligent, voice-guided navigation tools for the visually impaired.
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

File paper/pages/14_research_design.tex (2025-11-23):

\subsection{Research Design/Methods}

This research follows a mixed method design in data collection such as using quantitative data in measuring the accuracy and speed of the device in conveying information, and qualitative data in measuring the comfortability and acclimation of users towards using the device.

% This research implements an experimental and iterative prototyping research focused on developing and testing the wearable AIoT-based visual sensory substition device. This is done by following a development methodology which is similar to the engineering design cycle as seen in figure \ref{fig:researchcycle}.

% \begin{figure}[H]
%     \centering
%     \caption{Development Methodology of the research}
%     \includegraphics[width=\linewidth]{assets/research_cycle.png}
%     \textbf{Source:} \href{https://pressbooks.openeducationalberta.ca/researchasconversationandcommunication/chapter/chapter-1/}{openeducationalberta.ca} 
%     \label{fig:researchcycle}
% \end{figure}
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

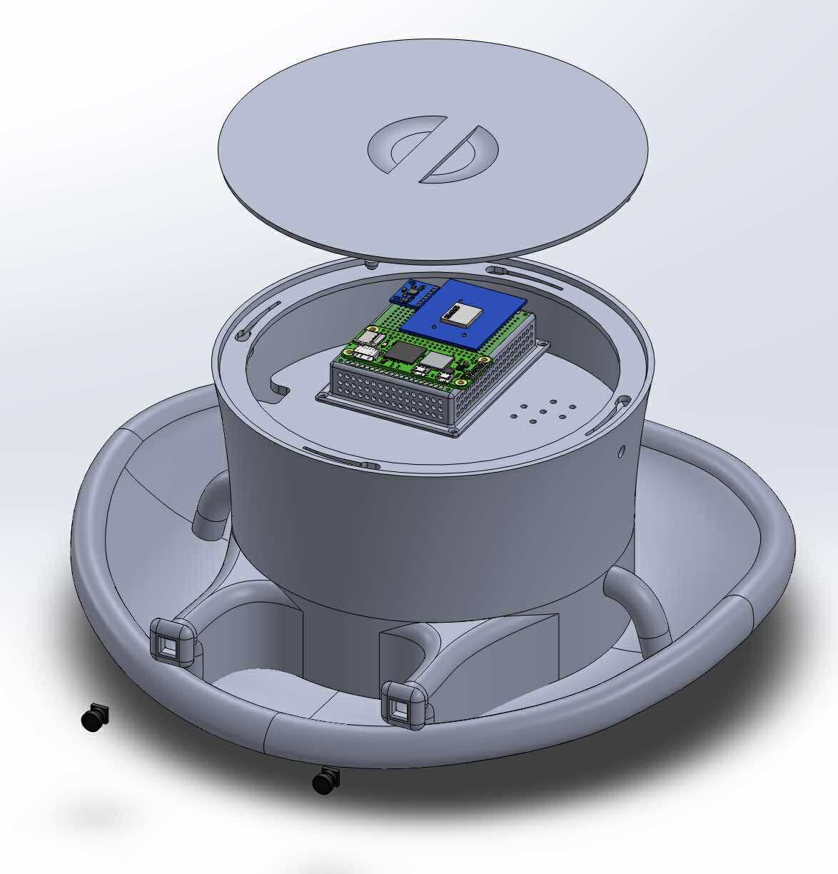
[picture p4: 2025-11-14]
paper/assets/3d.png

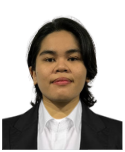
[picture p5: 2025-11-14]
paper/assets/pabito.png

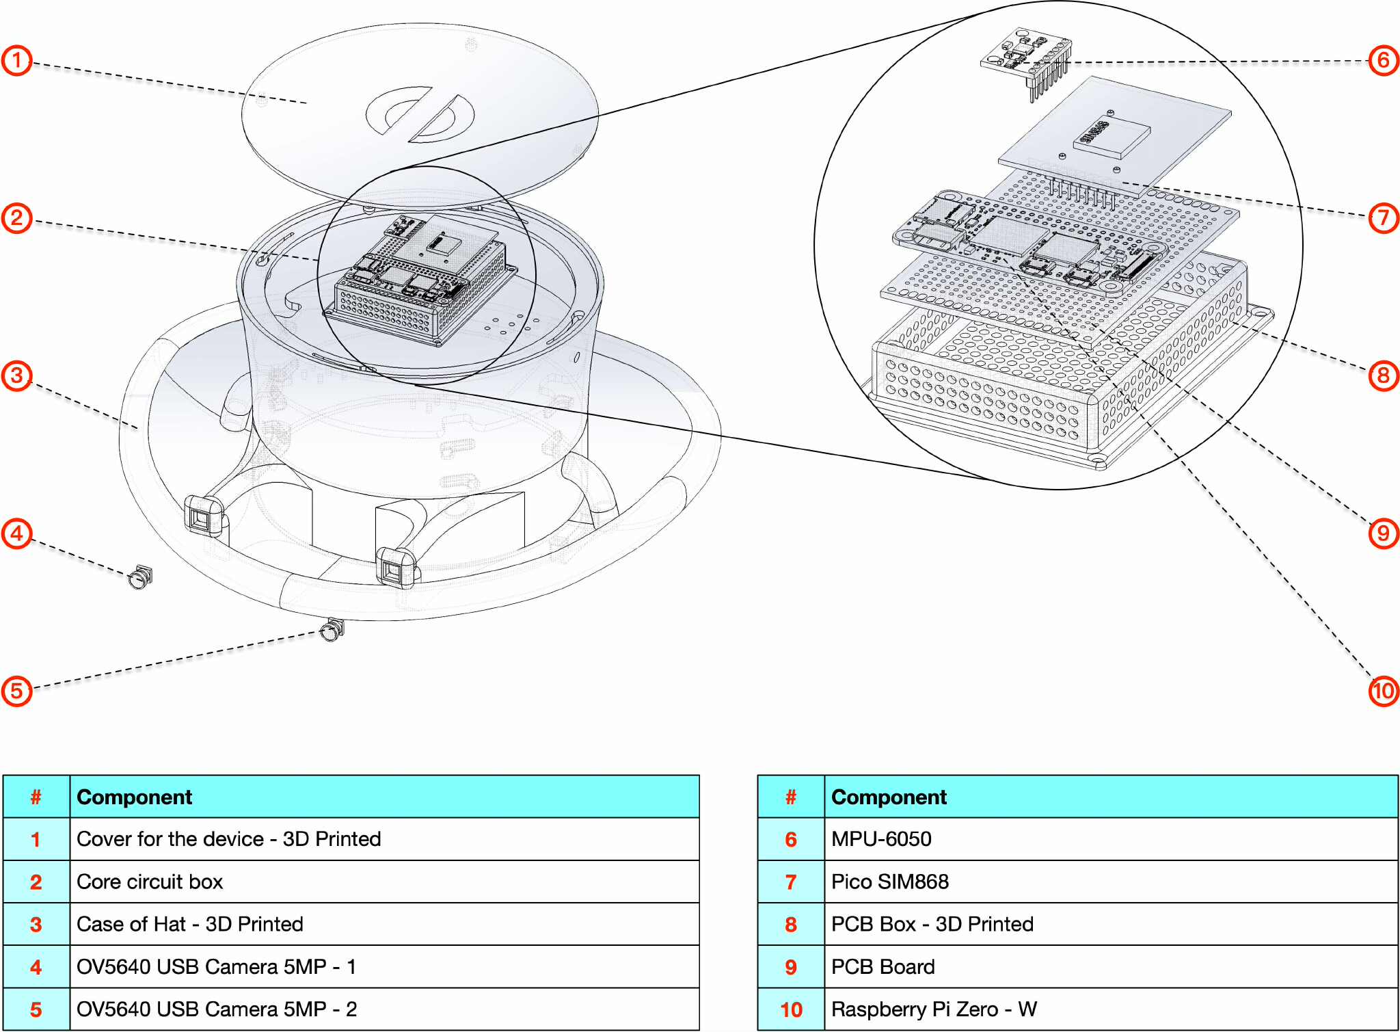
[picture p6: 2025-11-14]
paper/assets/wireframe.jpg

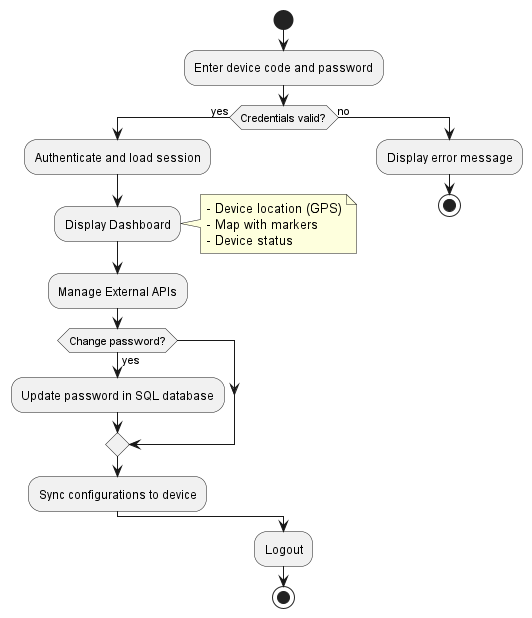
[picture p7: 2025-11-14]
paper/assets/uml-4.png

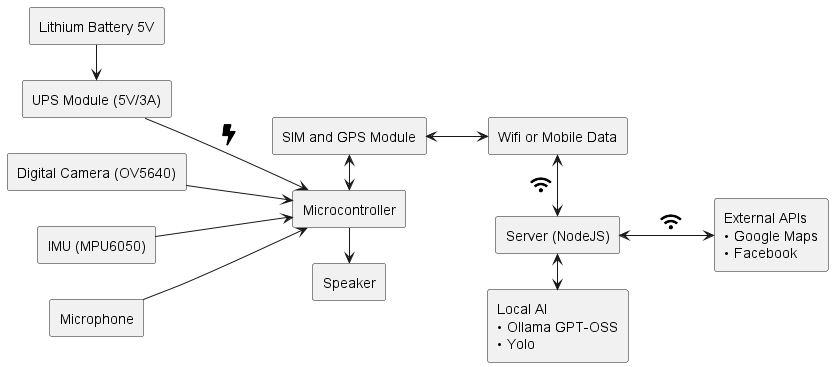
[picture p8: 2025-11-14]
paper/assets/uml-2.png

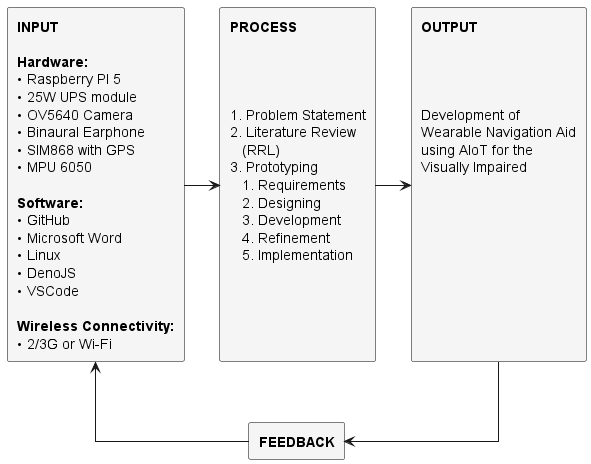
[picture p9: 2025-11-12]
paper/assets/uml-1.png

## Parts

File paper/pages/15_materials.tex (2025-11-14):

\subsection{Materials and Requirements} % Materials and Equipments

% System Requirements
% = Wireframes both hardware and software interace
%\subsubsection{Materials and Processes}
The World Navigation Hat operates through a multi-stage processing pipeline that begins with data acquisition and culminates in audio feedback delivery. The Orange Pi Zero 2W microcontroller, powered by a 5V/3A UPS module, serves as the central processing unit that orchestrates all system operations. The process initiates with stereo image capture from dual OV5640 USB cameras positioned 10 cm apart, providing 5MP resolution at 160° field of view for photogrammetry operations. Concurrently, the MPU6050 Inertial Measurement Unit tracks head motion and orientation to align the virtual environment with the user's vestibular senses, preventing sensory conflicts. Audio input is captured through an earphone microphone for voice command recognition. Five primary applications run simultaneously on the device:

\begin{enumerate}
    \item Photogrammetry processing that converts 2D stereo images into depth maps and 3D point clouds using stereo disparity calculations
    \item Human visual sense emulation pipeline that implements foveation, selective attention, and scene gist extraction to generate necessary audio cues while minimizing cognitive overload
    \item MediaPipe AI for real-time hand gesture recognition enabling touchless device control
    \item WhisperX voice recognition activated by specific hand gestures for command input
    \item modular framework allowing custom applications to integrate into the main pipeline with connection to the main server through standard APIs
\end{enumerate}
Processed data is transmitted via the SIM868 module (supporting 2G/3G cellular or Wi-Fi connectivity) to a NodeJS server infrastructure that handles additional computational tasks including Ollama for large language model processing, YOLO for advanced object detection, Puppeteer for web automation, external API integration (Google Maps, Meta platforms), SQL database management, and HTTP server operations for client-server communication.

\subsubsection{Hardware Material}
The hardware architecture integrates several critical components optimized for portable wearable computing. The Orange Pi Zero 2W single-board computer features a quad-core ARM Cortex-A53 processor with 512MB/1GB RAM options, providing sufficient computational power for real-time computer vision tasks while maintaining low power consumption suitable for battery operation. Two OV5640 USB cameras serve as the stereo vision system, each delivering 5-megapixel resolution with a 160° field of view and positioned with a 10 cm baseline to enable accurate depth estimation through stereo disparity calculations. The MPU6050 6-axis Inertial Measurement Unit combines a 3-axis gyroscope and 3-axis accelerometer, providing motion tracking data at high refresh rates to synchronize the virtual environment with user head movements. The SIM868 development board integrates GSM/GPRS/GPS functionality, enabling both outdoor navigation through GPS positioning and cellular data connectivity (2G/3G) for server communication when Wi-Fi is unavailable. An Onyehn TRRS audio module facilitates bidirectional audio communication, connecting both speaker output for audio cues and microphone input for voice commands through standard 3.5mm earphone jacks. Power management is handled by a custom UPS module accepting 5V/3A input, featuring lithium battery charging circuits (supporting 18650 or similar rechargeable cells) and voltage regulation to ensure stable operation during mobile use. All components are mounted on a custom-designed hat frame measuring 333.38 mm in length with integrated cable management and component housings to maintain ergonomic comfort during extended wear.

\subsubsection{Software Specification}
The software ecosystem operates across two primary environments: client-side processing on the Orange Pi Zero 2W and server-side operations on a NodeJS platform. The client-side implementation utilizes Python 3.x as the primary programming language, leveraging OpenCV (cv2) for image acquisition, preprocessing, and stereo vision algorithms including stereo calibration, rectification, and disparity map generation. NumPy provides optimized numerical computing for point cloud transformations, matrix operations in photogrammetry calculations (applying the stereo projection matrix Q to depth maps), and efficient array manipulations for real-time processing. Matplotlib enables visualization during development and debugging phases, generating spectrograms for audio cue analysis and 3D scatter plots for point cloud verification. MediaPipe framework implements hand gesture recognition through pre-trained machine learning models optimized for mobile deployment, detecting key hand landmarks and classifying gestures with minimal latency. PyTorch serves as the deep learning backend for custom neural network implementations, including depth estimation refinement models and audio generation networks that emulate human auditory processing. Additional Python libraries include SciPy for signal processing (audio synthesis, filtering), librosa for audio feature extraction, and pyserial for communication with peripheral modules (SIM868, MPU6050). The server-side infrastructure runs NodeJS with Express framework for HTTP server operations, handling REST API endpoints for client requests, managing WebSocket connections for real-time bidirectional communication, and coordinating database operations through SQL query execution. Ollama integration enables on-device large language model inference for natural language understanding and context-aware assistance, while YOLO (You Only Look Once) models provide high-speed object detection and classification when additional visual recognition is required beyond the client-side capabilities. Puppeteer automates web browser interactions, enabling the device to fetch real-time information from web services and interact with digital environments for enhanced navigation support.
The development workflow integrates multiple productivity and collaboration tools to streamline project organization, documentation, and version control. Visual Studio Code (VSCode) serves as the primary integrated development environment (IDE), providing syntax highlighting for Python and JavaScript, integrated terminal access for remote SSH connections to the Orange Pi Zero 2W, Git integration for version control operations, and extensive extension support including Python linters (pylint, flake8), formatters (black, autopep8), and remote development extensions for direct editing on embedded systems. GitHub hosts the project repositories, implementing version control through Git for both client-side Python applications and server-side NodeJS code, facilitating collaborative development among team members through branch management, pull requests, code reviews, and issue tracking for bug reports and feature requests. LaTeX document preparation system generates the formal thesis documentation with precise mathematical typesetting for equations including stereo disparity formulas, point cloud projection matrices, and depth-to-audio mapping functions, ensuring professional formatting standards for academic submission while maintaining version-controlled .tex source files. Google Docs provides real-time collaborative editing for preliminary research documentation, literature review organization, meeting notes, and draft content development, enabling simultaneous multi-user editing with comment threads for peer feedback and revision tracking. Microsoft Office suite (Word, Excel, PowerPoint) supports supplementary documentation tasks including formatted research proposals, data analysis spreadsheets for experimental results (accuracy measurements, user feedback surveys, performance benchmarks), and presentation materials for design reviews and project demonstrations. Claude AI assists throughout the development lifecycle as an AI-powered coding assistant and research tool, providing algorithm optimization suggestions, debugging support for complex stereo vision calculations, documentation generation for API endpoints and function specifications, literature synthesis for theoretical framework development, and technical writing refinement for thesis chapters. This integrated software toolchain ensures systematic project management from initial concept through final implementation, maintaining code quality through version control, facilitating team collaboration across distributed work environments, and producing comprehensive documentation that meets both academic standards and technical reproducibility requirements.

\subsubsection{Library and Board Managers}
Development and deployment require specific software dependencies managed through multiple package systems across different platforms. For the Orange Pi Zero 2W running Armbian or Ubuntu-based distributions, the APT package manager handles system-level dependencies including Python 3.x development packages (python3-dev, python3-pip), OpenCV system libraries (libopencv-dev, python3-opencv), audio system requirements (libasound2-dev, portaudio19-dev), and USB camera support utilities (v4l-utils). Python package management through pip3 installs critical libraries with specific version constraints: opencv-python ($\geq 4.5.0$) for computer vision operations, numpy ($\geq 1.21.0$) for numerical computing, mediapipe ($\geq 0.8.0$) for hand tracking AI models, torch ($\geq 1.10.0$) with ARM-compatible builds for deep learning inference, sounddevice and soundfile for audio I/O operations, pyserial ($\geq 3.5$) for hardware communication, and requests for HTTP client functionality. Arduino IDE or Platform IO manages firmware for any auxiliary microcontrollers if implemented, including board definitions for custom boards and library dependencies for sensor communication protocols (I2C for MPU6050, SPI for peripheral modules). The NodeJS ecosystem uses npm (Node Package Manager) to install server-side dependencies: express ($\geq 4.18.0$) for web server framework, ws for WebSocket implementation, sequelize or knex for SQL database ORM, axios for HTTP client operations to external APIs, and child\_process management for spawning Ollama and YOLO processes. Board-specific configurations require Orange Pi GPIO libraries (OrangePi.GPIO or wiringOP) for direct hardware pin control if needed, and kernel module loading for camera interfaces (ensuring proper v4l2 driver support for OV5640 USB cameras through modprobe configurations). Git version control manages source code across development iterations, with repositories configured for both client and server codebases, while systemd service configurations enable automatic startup of critical applications on boot for production deployment.

\subsubsection{Other Materials/Equipment/Devices}
Beyond the core electronic components, the project requires supplementary materials and equipment for fabrication, testing, and evaluation. The physical enclosure utilizes 3D-printed components designed in CAD software, with wireframe dimensions of 333.38 mm length, 197.50 mm width, and component-specific mounting features including camera housings with precise 10 cm spacing alignment, ventilated sections for heat dissipation from processing components, and cable routing channels. The 3D printing process uses PLA or PETG filament for structural components requiring strength and thermal stability, with print settings optimized for layer adhesion and surface finish to ensure user comfort during extended wear. A standard baseball cap or adjustable hat frame serves as the foundation for component integration, providing familiar ergonomics and adjustable sizing through standard strap mechanisms. Micro SD card (minimum 32GB Class 10 or UHS-I) stores the operating system, application code, and temporary data cache for the Orange Pi Zero 2W, while a micro SIM card with active data plan enables cellular connectivity through the SIM868 module. Lithium-ion battery cells (18650 format, 3.7V nominal, minimum 2500mAh capacity) power the UPS module, with appropriate battery holders and spot-welded connections ensuring reliable electrical contact and mechanical stability. USB-C cable provides charging interface for the UPS module, allowing users to recharge using standard mobile phone chargers or power banks. Testing and evaluation equipment includes a reference measuring device (laser rangefinder or calibrated ruler) for depth accuracy validation, comparing predicted distances from stereo disparity calculations against ground truth measurements across various ranges (0.5m to 5m typical operating distance). A standardized navigation course with marked obstacles, varying textures, and elevation changes facilitates user testing protocols for evaluating device effectiveness. Audio analysis equipment (reference microphone, audio interface, spectrum analyzer software) characterizes the generated audio cues for frequency response, dynamic range, and spatial positioning accuracy. Additionally, development workstations (laptop/desktop computers with Linux or Windows OS) run cross-compilation toolchains, debugging interfaces (SSH, serial console), and simulation environments for algorithm validation before hardware deployment. Safety equipment for user testing includes protective padding for obstacle courses, first aid supplies, and emergency communication devices in compliance with IRB-approved testing protocols outlined in the ethical considerations section.

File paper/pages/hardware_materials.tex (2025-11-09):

% Hardware Material Specification
\subsection{Hardware Material Specification}

% \begin{figure}[htbp]
%     \centering
%     \begin{circuitikz}[x=1cm,y=1cm]
%         % ----- RASPBERRY PI ZERO 2W ----- %
%         \draw[thick] (0,0) rectangle (3,6.5);
%         \node[anchor=center] at (1.5,6.8) {\tiny Raspberry PI Zero 2W};
%         \node[anchor=center] at (1.5,-0.2) {\tiny 30mm x 65mm};
%         % SD CARD
%         \draw[thick] (0.71,0.16) -- (0.71,1.27) -- (1.91,1.27) -- (1.91,0.16) -- (1.69,0.16) -- (1.69,0.29) -- (0.82,0.29) -- (0.82,0.16)  -- (0.71,0.16);
%         % ICS
%         \draw[thick] (0.84,2) rectangle (2.35,3.5);
%         \draw[thick] (1.03,3.83) rectangle (2.25,5);
%         % PORTS
%         \filldraw[thick,fill=white] (2.3,0.7) rectangle (3.13,1.81);
%         \filldraw[thick,fill=white] (2.6,3.83) rectangle (3.13,4.53);
%         \filldraw[thick,fill=white] (2.6,5) rectangle (3.13,5.8);
%         \filldraw[thick,fill=white] (0.71,6.2) rectangle (2.28,6.62);
%         % PINS
%         \foreach \x in {0,1}{ \foreach \y in {0,...,19}{
%             \draw[thick] (0.22+0.25*\x, 0.86+0.25*\y) circle (0.08);
%         }}

%         % ----- SIM868 ----- %
%         \draw[thick] (-0.8,0) rectangle (-5.9,4.0);
%         \foreach \y in {0,...,7}{
%             \draw[thick] (-0.97,1.29+0.25*\y) circle (0.08);
%         }
%         % SIM CARD
%         %\draw[thick] (-4.25,2.38) -- (-5.75,2.39) -- (-5.75,3.95) -- (-5.36,3.95) -- controls (-4.915,3) -- (-4.47,3.95);
%     \end{circuitikz}
%     \caption{Skematic Diagram of Device}
%     \label{fig:skematic}
% \end{figure}

\begin{table}[h]
    \centering
    \begin{tabular}{|c|l|l|}
        \hline
        \textbf{Quantity} & \textbf{Material} & \textbf{Description} \\
        \hline
        1 & Raspberry PI Zero 2W  & Main microcontroller \\
        1 & USB-C 5A/3A UPS Module & Power supply \\
        2 & OV5640 USB Camera 5MP and 160\degree FOV & Image input \\
        1 & Wired binaural earphone w/ microphone & Audio input/output \\
        1 & SIM868 development board & Phone features (Internet, GPS, etc.) \\
        1 & MPU 6050 & Orientation detection \\
        1 & Female audio jack module & Connects earphone with Raspberry pi \\
        1 & Micro SIM card & Connects to provider for internet \\
        1 & Micro SD card & Stores operating system and data \\
        2 & 18650 Li-ion Rechargeable Battery & Power storage \\
        \hline
    \end{tabular}
    \caption{Hardware Specification}
    \label{tab:hardware}
\end{table}

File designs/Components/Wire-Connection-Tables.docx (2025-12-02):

1.

Wire Color | From (UPS Module) | To (Orange Pi Zero 2W) | Function
Red | UPS+ (Top Right Pad) | Pin 2 (Physical Pin 2) | +5V Power Input
Black | -UPS (Bottom Right Pad) | Pin 6 (Physical Pin 6) | Ground (GND)

2.

Wire Color | From (SIM868) | To (Orange Pi Zero 2W) | Function
Red | VCC (Pin 5) | Pin 2 (Physical Pin 2) | 5V Power Input
Black | GND (Pin 4) | Pin 6 (Physical Pin 6) | Ground (GND)
Blue | TXD (Pin 3) | Pin 8 (Physical Pin 8) | UART0_TX (Serial Transmit)
Blue | RXD (Pin 2) | Pin 10 (Physical Pin 10) | UART0_RX (Serial Receive)
Blue | PWREN (Pin 1) | Pin 12 (Physical Pin 12) | GPIO (PH2) (Power Enable Control)

3.

Wire Color | From (MPU9250) | To (Orange Pi Zero 2W) | Function
Red | VCC | Pin 1 | 3.3V Power
Blue | SDA | Pin 3 | I2C SDA (Data)
Blue | SCL | Pin 5 | I2C SCL (Clock)
Black | GND | Pin 9 | Ground (GND)

4.

Wire Color | From (MPU6050) | To (Orange Pi Zero 2W) | Function
Red | VCC | Pin 1 | 3.3V Power
Blue | SDA | Pin 3 | I2C SDA (Data)
Blue | SCL | Pin 5 | I2C SCL (Clock)
Black | GND | Pin 9 | Ground (GND)

5.

Wire/Cable | Connection Type | Description
24-Pin Ribbon Cable | Interface | Connects the 24 Pin Interface on the Orange Pi Zero 2W to the 24 Pin Interface on the Expansion Board.

6.

Wire/Cable | From (Expansion Board USB) | To (DVP-to-USB Bridge) | Function
Blue Trace 1 | USB 5V | 5V | Power Supply
Blue Trace 2 | USB D- | D- | USB Data -
Blue Trace 3 | USB D+ | D+ | USB Data +
Blue Trace 4 | USB GND | GND | Ground

Wire/Cable | From (DVP-to-USB Bridge) | To (OV5640 Camera) | Function
Ribbon Cable | FPC Connector | FPC Connector | DVP Interface (Video Data)

7.

Component | Connected To | Description
3.5mm Earphones | Expansion Board Audio Jack | Standard analog audio output for music or system sounds.

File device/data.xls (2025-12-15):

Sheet: Calibration
Baseline (cm) |  | Pixel Error (pixels) |  |  | Calibration
Actual | Calculated | Left | Right | Both | Points | Curve fitted equation
13 | 12.5 | 2.5872 | 2.4419 | 2.981 | 648
14 | 13.77 | 2.4992 | 2.3216 | 2.6772 | 648 | Derivative of equation
15 | 14.61 | 2.257 | 2.5203 | 2.5728 | 648
16 | 15.52 | 2.487 | 2.364 | 2.5971 | 648 | Optimal baseline (cm)
17 | 16.27 | 2.7463 | 2.32 | 2.781 | 648 | 15.34226012
18 | 17.13 | 2.7551 | 2.4405 | 3.0835 | 648
19 | 17.87 | 2.7613 | 2.6744 | 3.5412 | 648

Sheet: Tasks
Task | Success Rate (%) | Average Time (s) | Error Count | User Rating (1-5) | Description
Using the device's features | 95 | 15 | 0.2 | 4.6 | Users know how to trigger different device modes by head movement (e.g., downward for audio depth map, right-down for gesture mode).
Identify general room outline | 85 | 45 | 1.1 | 4.2 | Users can explain the general shape of the room (e.g., nearby walls, furniture) based on audio feedback from the depth map.
Identify direction of movement | 90 | 20 | 0.5 | 4.4 | Users can point to the direction of movement (e.g., a person walking left-to-right) using audio cues for proximity and frequency.
Walk through an open door | 80 | 60 | 0.8 | 4 | Users can roam around a room and enter a door without hitting anything, relying on stereo depth map audio.
Use app (mockup) by gesture | 90 | 25 | 0.3 | 4.5 | Users can trigger hand gesture mode (right-down head tilt) to activate and stop a mock call app
Prolonged navigation without fatigue | 75 | 600 | 1.5 | 3.8 | Users navigate a multi-room course for 10 minutes using audio depth feedback; report fatigue levels post-task (overload measured by ability to maintain performance without breaks).
Selective attention to filtered data | 85 | 30 | 0.7 | 4.3 | Users identify a specific moving object (e.g., a ball rolling) amid static background, while the device fades repeated areas to reduce overload; tested in a cluttered room.
Device integration and usability survey | 90 |  |  | 4.1 | After 20 minutes of mixed use, users rate overall integration (comfort, modularity for personal needs, willingness to use daily) on a scale; includes open feedback on fatigue and overload.

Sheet: Survey
Question | 5 | 4 | 3 | 2 | 1 | Average
I. Perceived Usefulness (PU)
I.A. Device Performance
The device is useful for improving my Navigation and obstacle detection.
The AI processing (e.g., text/object/face recognition) helps me perform tasks more Effectively.
The AI processing (e.g., text/object/face recognition) helps me perform tasks more Effectively.
I.B. Sensory Overload
In complex environments (e.g., crowded areas), the device reduces sensory overload (e.g. too much conflicting or overwhelming information) by prioritizing useful cues.
The device helps me focus on important obstacles without overwhelming me with unnecessary details.
I.C Sensory Fatigue
The continuous audio cues support effective navigation without tiring me out.
The device's processing speed (e.g., FPS) provides timely feedback, making long-term use more useful.
I.D. Sensory Integration
The audio cues accurately reflect combined data from cameras and motion sensors, aiding navigation
Overall, the unified sensory inputs make the device more effective for interpreting my environment.
II. Perceived Ease of Use (PEOU)
II.A. Device Performance
The gesture controls (e.g., hand waves or pinches) are easy to learn and use.
The battery life (e.g., 7 hours) makes the device convenient for daily use without frequent recharging.
II.B. Sensory Overload
The audio cues are clear and easy to interpret without causing confusion.
I can easily adjust the audio settings to prevent overload.
II.C. Sensory Fatigue
After using the device for 30 minutes or more, I do not feel mentally fatigued from the audio feedback.
I do not need frequent breaks from the device to avoid sensory fatigue.
II.D. Sensory Integration
There are no discrepancies or delays when switching between modes (e.g., photogrammetry to AI recognition).
The device seamlessly integrates gesture commands with audio outputs
III. Attitude Towards Using (ATU)
I have a positive attitude toward using the navigation hat regularly.
The device's sensory features (e.g., audio cues, integration) make me feel confident in navigating independently.
Overall, I enjoy using the device despite any challenges with overload or Fatigue.
IV. Behavioral Intention (BI)
I intend to use the navigation hat in my daily navigation tasks.
I would recommend the navigation hat to other visually impaired individuals.
V. General Feedback
What is your overall satisfaction with the device?
Any suggestions for improving the device and its PU, PEOU, ATU, or BI based on the four topics?

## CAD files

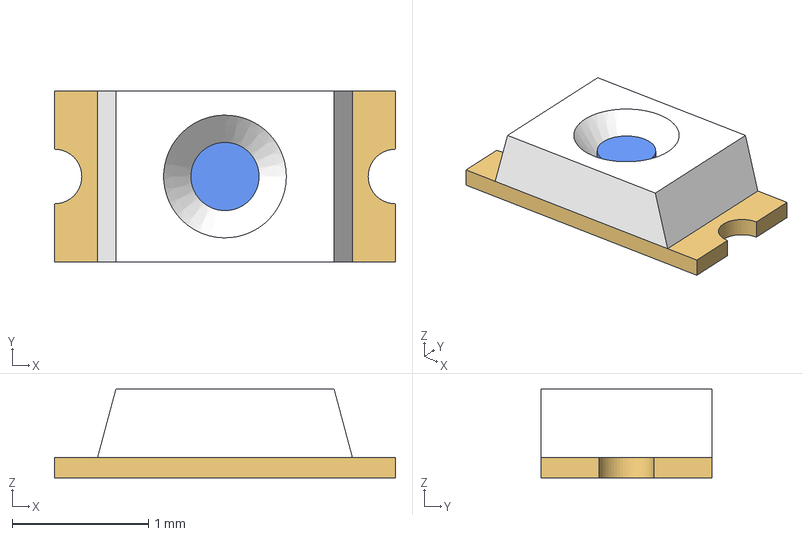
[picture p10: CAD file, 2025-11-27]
designs/3D Models/mpu6050/FreeCAD Files/SM LED.FCStd
2.50 x 1.25 x 0.65 mm

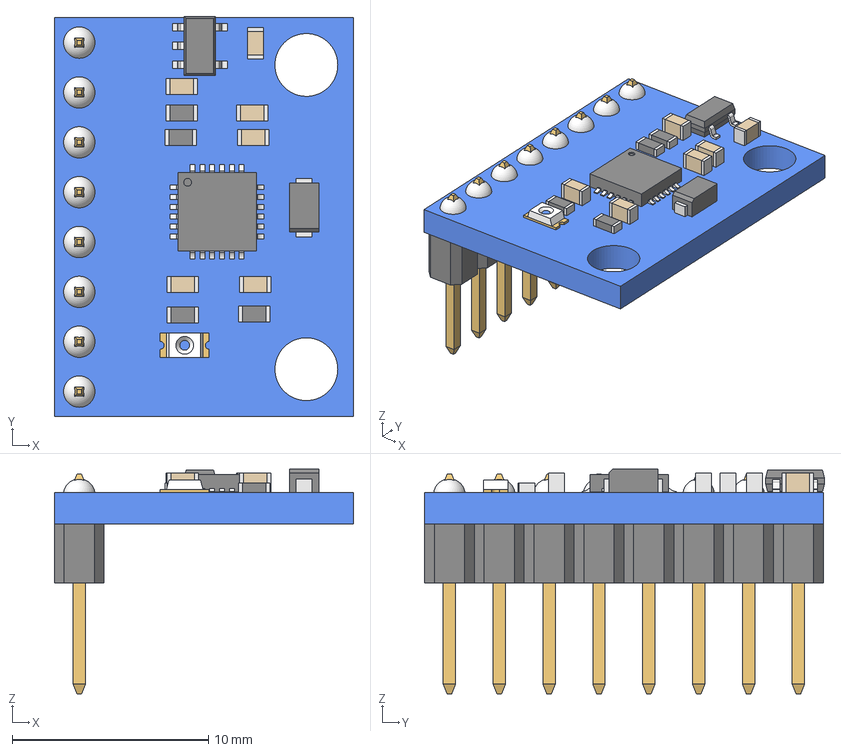
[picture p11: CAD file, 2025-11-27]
designs/3D Models/mpu6050/mpu6050.step
15.3 x 20.4 x 11.5 mm
Board_001
SOT25_001
0603 Capacitor_001
0603 Capacitor_002
0603 Capacitor_003
0603 Capacitor_004
0603 Capacitor_005
0603 Capacitor_006
0603 Resistor_001
0603 Resistor_002
0603 Resistor_003
0603 Resistor_004
SM LED_001
Diode 2_001
24 QFN_001
1x8 Male Header_001

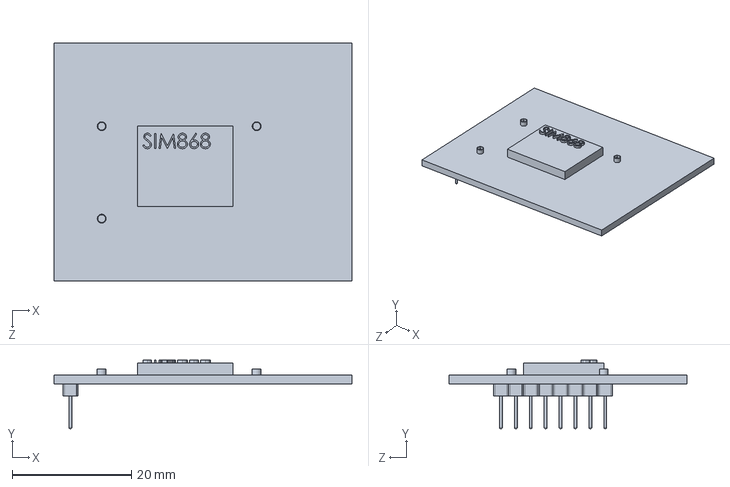
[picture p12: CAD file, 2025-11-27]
designs/3D Models/sim868.SLDPRT
50.0 x 11.5 x 40.0 mm

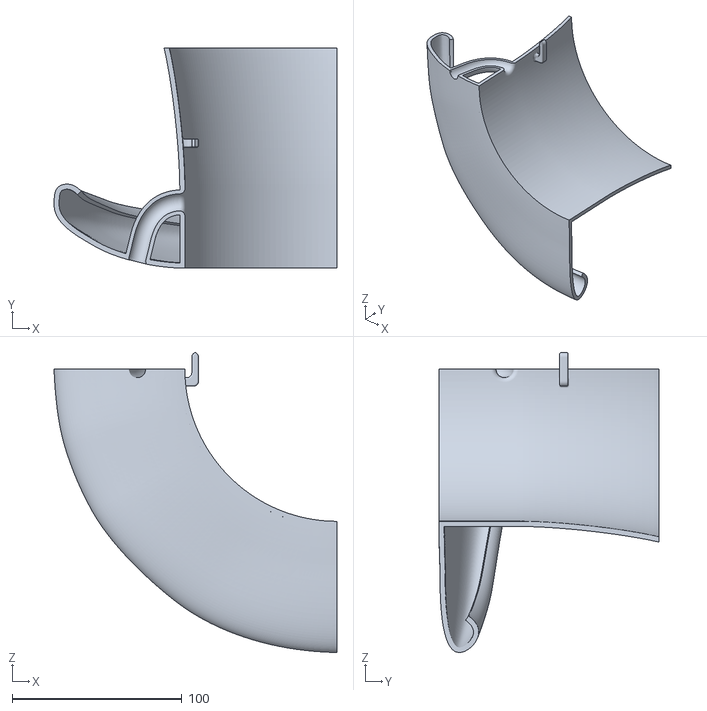
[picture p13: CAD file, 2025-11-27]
designs/3D Models/STLs/hat-part-1.STL
166.5 x 129.5 x 176.5

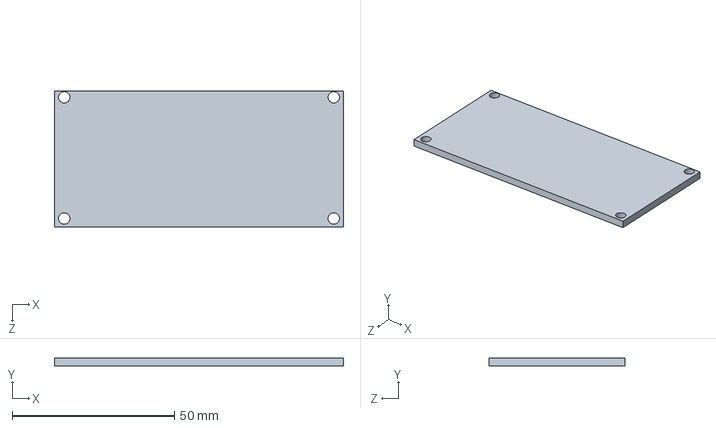
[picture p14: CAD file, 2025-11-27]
designs/3D Models/ups/ups.SLDPRT
89.0 x 2.50 x 42.0 mm

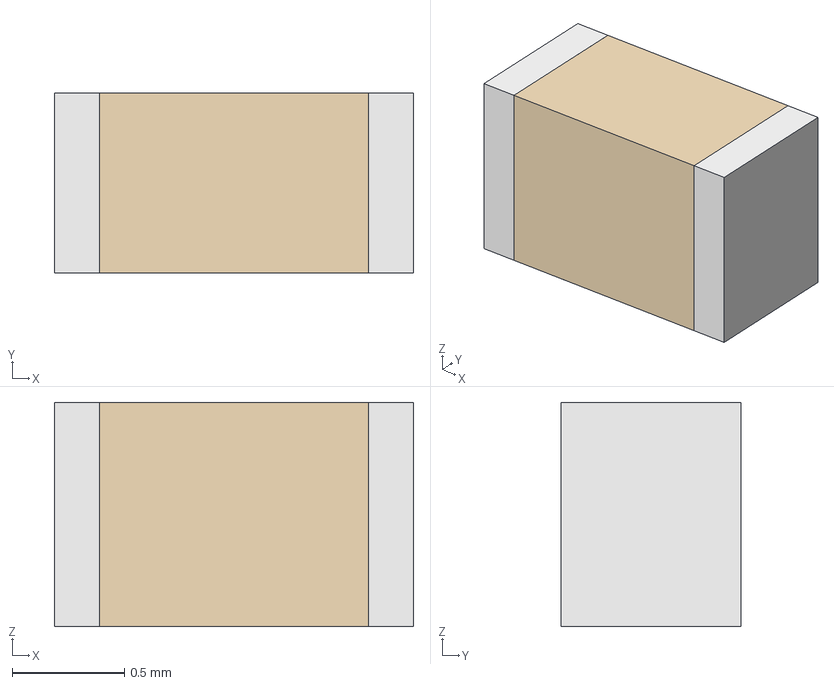
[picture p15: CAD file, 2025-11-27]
designs/3D Models/mpu6050/FreeCAD Files/0603 Capacitor.FCStd
1.60 x 0.8 x 1.00 mm
Body001 (Mirror #1)

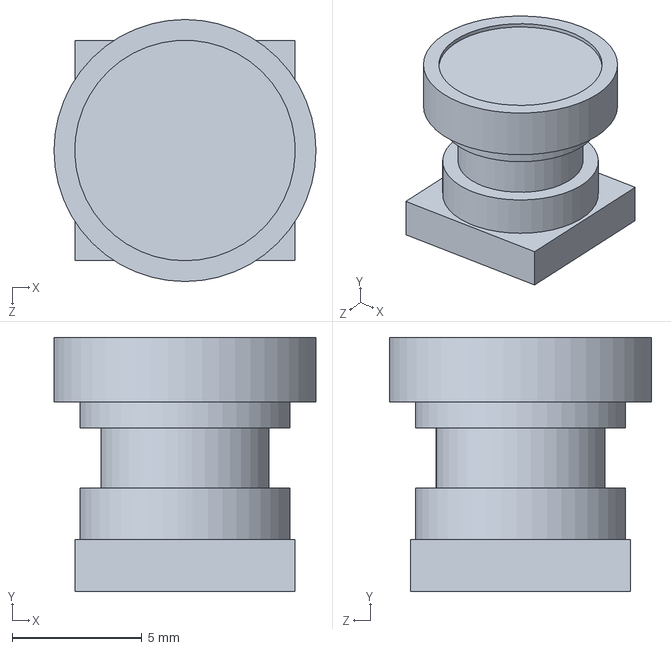
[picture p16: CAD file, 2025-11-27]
designs/3D Models/OV5640-camera.SLDPRT
10.1 x 9.80 x 10.1 mm

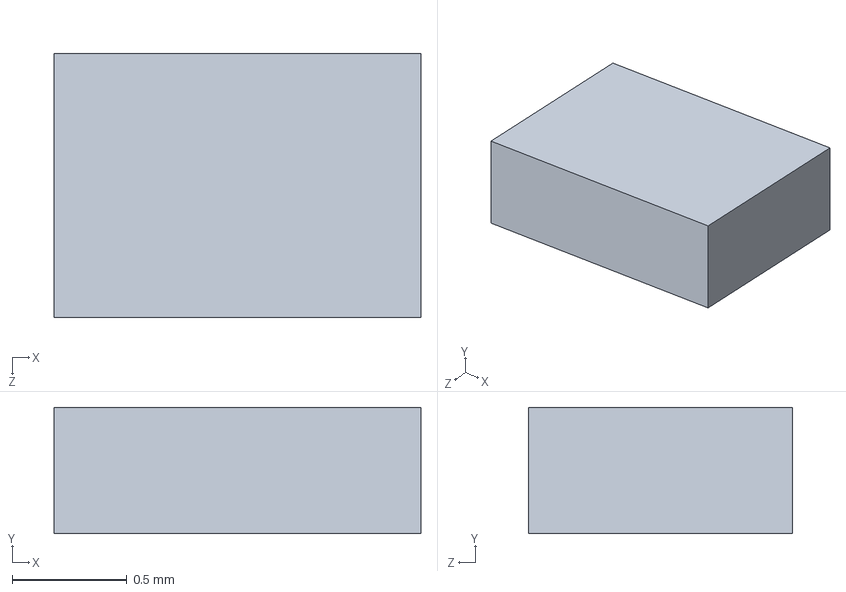
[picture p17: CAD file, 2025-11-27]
designs/3D Models/raspberry-pi-zero-2-w/LED, Raspberry Pi Zero 2 W.SLDPRT
1.60 x 0.55 x 1.15 mm

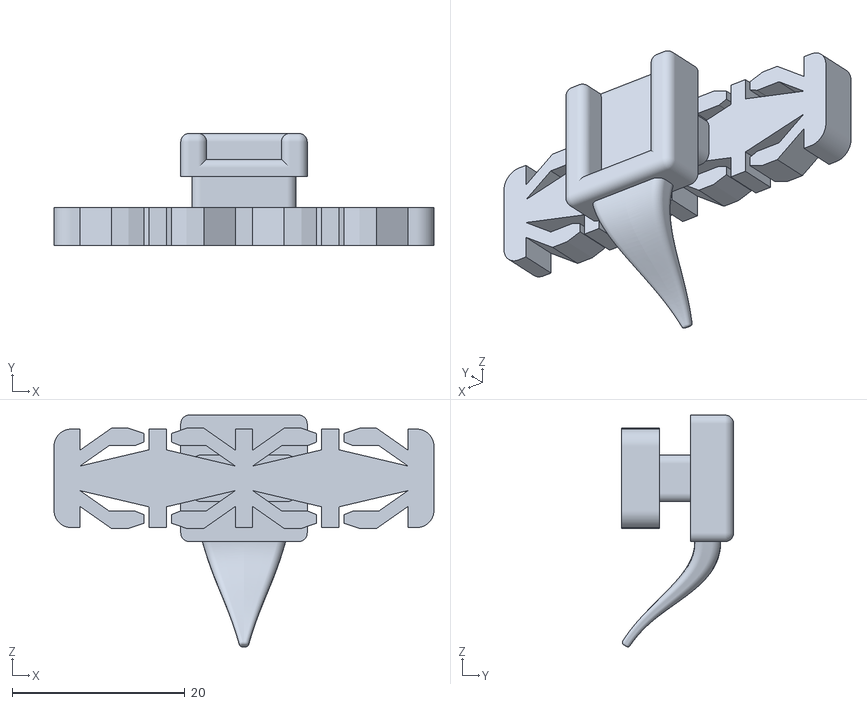
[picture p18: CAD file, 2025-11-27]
designs/3D Models/calibrate-tool/calibrate-solid.STL
44.0 x 13.0 x 26.8

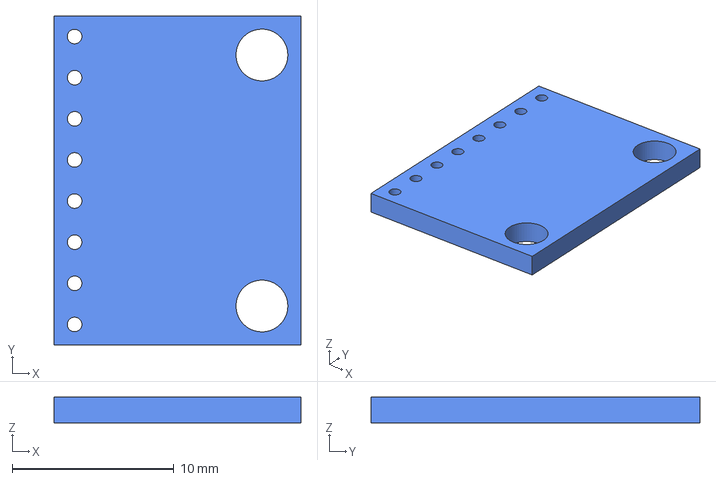
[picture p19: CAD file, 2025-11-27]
designs/3D Models/mpu6050/FreeCAD Files/Board.FCStd
15.2 x 20.3 x 1.60 mm

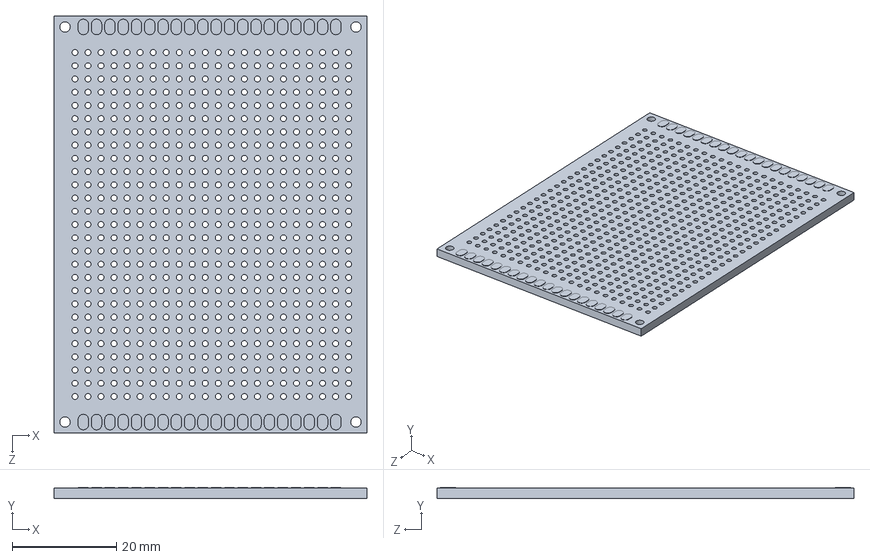
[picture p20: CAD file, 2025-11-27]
designs/3D Models/pcb.SLDPRT
60.0 x 2.10 x 80.0 mm

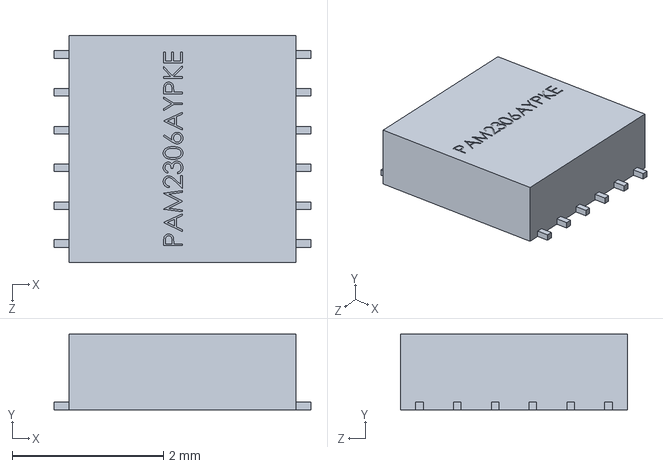
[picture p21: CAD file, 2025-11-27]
designs/3D Models/raspberry-pi-zero-2-w/PAM2306AYPKE, Switching Voltage Regulators Dual PWM Step-Down 40uA 1A 1.5MHz, Raspberry Pi Zero 2 W.SLDPRT
3.40 x 1.00 x 3.00 mm

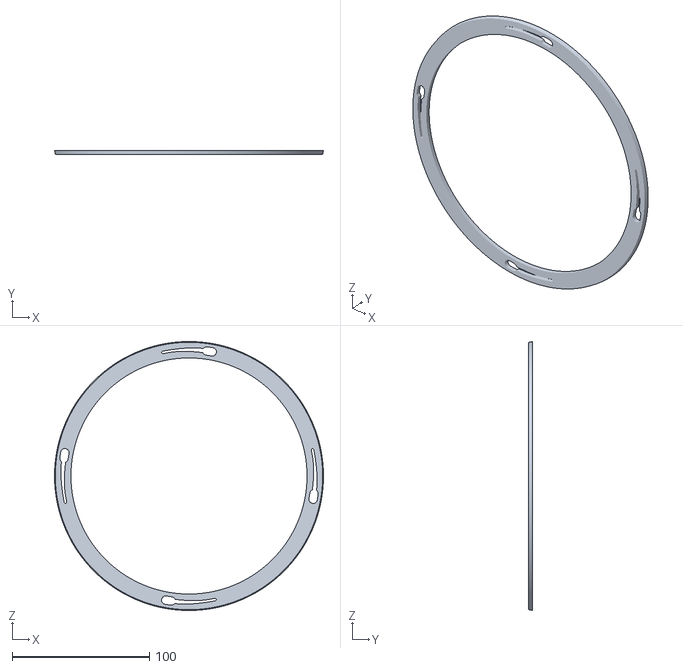
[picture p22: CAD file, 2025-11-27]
designs/3D Models/STLs/hat-ring.STL
196.0 x 3.00 x 196.0

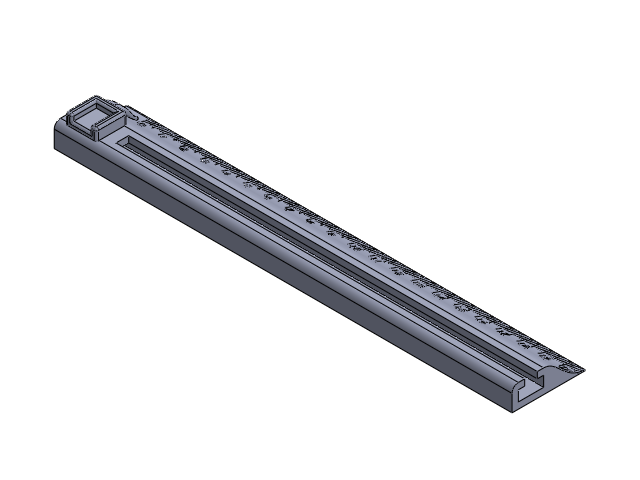
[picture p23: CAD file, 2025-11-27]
designs/3D Models/calibrate-tool/assem.SLDASM
rail

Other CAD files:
designs/3D Models/pcb_layouts.SLDASM
designs/3D Models/raspberry-pi-zero-2-w/Raspberry Pi Zero 2 W.SLDASM
designs/3D Models/calibrate-tool/rail-design.SLDPRT
designs/3D Models/STLs/hat-part-3.STL
designs/3D Models/OV5640-pcb.SLDPRT
designs/3D Models/STLs/hat-clamp.STL
designs/3D Models/STLs/hat-cover.STL
designs/3D Models/STLs/hat-plate.STL
designs/3D Models/calibrate-tool/calibrate-rail.STL
designs/3D Models/calibrate-tool/rail.SLDPRT
designs/3D Models/calibrate-tool/solid.SLDPRT
designs/3D Models/mpu6050/FreeCAD Files/0603 Resistor.FCStd
designs/3D Models/mpu6050/FreeCAD Files/1x8 Male Header.FCStd
designs/3D Models/mpu6050/FreeCAD Files/24 QFN.FCStd
designs/3D Models/mpu6050/FreeCAD Files/8 Pos Socket Header.FCStd
designs/3D Models/mpu6050/FreeCAD Files/Diode 2.FCStd
designs/3D Models/mpu6050/FreeCAD Files/M2 Nylon Flat Washer.FCStd
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

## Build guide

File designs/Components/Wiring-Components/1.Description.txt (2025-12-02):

The power system's primary design is a Battery-Centric Uninterruptible Power Supply (UPS) utilizing the 18650 5V/3A UPS Module and two (2) 18650 batteries for device operation.

The Orange Pi Zero 2W receives its 5V operating voltage from the UPS Module's power output terminals (labeled 5V+ and 5V-), which are connected to the Orange Pi's 5V and GND pins on its GPIO header:

1. Positive Connection: The 5V+ terminal (Red wire) on the UPS Module connects to the 5V supply pin on the Orange Pi's GPIO header.

2. Negative/Ground Connection: The 5V- terminal (Black wire) on the UPS Module connects to the GND (Ground) pin on the Orange Pi's GPIO header.

The critical function of this UPS Module is to draw power from the installed 18650 battery, regulate it to a stable 5V, and deliver it to the Orange Pi Zero 2W. This ensures that the device maintains continuous operation, directly powered by the battery, even if the main external power source is interrupted, thereby fulfilling the uninterruptible power supply function.

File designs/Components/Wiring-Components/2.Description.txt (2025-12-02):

This diagram illustrates the wired connection between the SIM868 GSM/GPRS/GNSS module and the Orange Pi Zero 2W, utilizing the Universal Asynchronous Receiver-Transmitter (UART) interface for serial communication, along with dedicated lines for power and system control. All physical connections are made through the General-Purpose Input/Output (GPIO) header of the Orange Pi Zero 2W.

Serial Communication (UART)
The primary four communication lines enable the Orange Pi Zero 2W to send AT commands and receive data from the SIM868 module:

1. SIM868 RXD to Orange Pi TXD: A Blue wire connects the SIM868's Receive Data (RXD) pin to a dedicated Transmit Data (TXD) pin on the Orange Pi's GPIO header.

2. SIM868 TXD to Orange Pi RXD: A Blue wire connects the SIM868's Transmit Data (TXD) pin to a dedicated Receive Data (RXD) pin on the Orange Pi's GPIO header.

3. SIM868 RTS to Orange Pi CTS: A Blue wire connects the SIM868's RTS (Request to Send) pin to the corresponding CTS (Clear to Send) pin on the Orange Pi.

4. SIM868 CTS to Orange Pi RTS: A Blue wire connects the SIM868's CTS pin to the corresponding RTS pin on the Orange Pi. These four lines collectively form the UART interface, including Hardware Flow Control (RTS/CTS) to ensure reliable data transfer.

Power and System Control
1. Power Input (V_IN): The Red wire connects the SIM868's V_IN pin to the 5V pin on the Orange Pi's GPIO header, providing the required operating voltage.

2. Ground (GND): The Black wire connects the SIM868's GND pin to a GND pin on the Orange Pi's GPIO header, establishing the necessary common electrical reference.

3. System Control (DTR): The Orange/Red wire connects the SIM868's DTR (Data Terminal Ready) pin to a designated GPIO pin on the Orange Pi. This connection is typically used for sleep/wake control or monitoring module status.

This comprehensive configuration enables the Orange Pi Zero 2W to leverage the SIM868 module for external communication services (cellular networking and GPS), making the single-board computer a mobile data platform.

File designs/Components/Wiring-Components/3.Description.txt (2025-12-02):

The MPU9250 Inertial Measurement Unit (IMU) module is connected to the Orange Pi Zero 2W using the Inter-Integrated Circuit (I2C) serial communication interface. This connection uses four wires routed directly through the Orange Pi's General-Purpose Input/Output (GPIO) header.

I2C Communication Lines

The I2C protocol enables data exchange between the master (Orange Pi) and the slave (MPU9250) using two signal lines:

Serial Clock (SCL): The Black wire connects the SCL pin on the MPU9250 module to the designated I2C Clock pin on the Orange Pi's GPIO header. This synchronizes the data transfer.

Serial Data (SDA): The Blue wire connects the SDA pin on the MPU9250 module to the designated I2C Data pin on the Orange Pi's GPIO header. This line carries the data packets.

Power Supply and Ground

The power connections ensure the sensor operates correctly:

Power (VCC): The Red wire connects the VCC pin on the MPU9250 module to the 3.3V pin on the Orange Pi's GPIO header, supplying the necessary operating voltage.

Ground (GND): The Black wire connects the GND pin on the MPU9250 module to a common GND pin on the Orange Pi's GPIO header, establishing the electrical reference.

This configuration allows the Orange Pi Zero 2W to read real-time motion and orientation data (accelerometer, gyroscope, and magnetometer) from the MPU9250 for system operation and processing.

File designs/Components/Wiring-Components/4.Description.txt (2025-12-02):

The MPU6050 Inertial Measurement Unit (IMU) module is connected to the Orange Pi Zero 2W using the Inter-Integrated Circuit (I2C) serial communication interface. This connection uses four wires routed directly through the Orange Pi's General-Purpose Input/Output (GPIO) header.

I2C Communication Lines

The I2C protocol enables data exchange between the master (Orange Pi) and the slave (MPU6050) using two signal lines:

Serial Clock (SCL): The Black wire connects the SCL pin on the MPU6050 module to the designated I2C Clock pin on the Orange Pi's GPIO header. This synchronizes the data transfer.

Serial Data (SDA): The Blue wire connects the SDA pin on the MPU6050 module to the designated I2C Data pin on the Orange Pi's GPIO header. This line carries the data packets.

Power Supply and Ground

The power connections ensure the sensor operates correctly:

Power (VCC): The Red wire connects the VCC pin on the MPU6050 module to the 3.3V pin on the Orange Pi's GPIO header, supplying the necessary operating voltage.

Ground (GND): The Black wire connects the GND pin on the MPU6050 module to a common GND pin on the Orange Pi's GPIO header, establishing the electrical reference.

This configuration allows the Orange Pi Zero 2W to read real-time motion and orientation data (accelerometer, gyroscope, and magnetometer) from the MPU6050 for system operation and processing.

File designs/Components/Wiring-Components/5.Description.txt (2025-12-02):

The connection between the Orange Pi Zero 2W and the Orange Pi Expansion Board is established via a single flexible ribbon cable, connecting their respective 24-pin interfaces.

The Orange Pi Zero 2W is connected to the Expansion Board using a 24-pin Flexible Printed Circuit (FPC) ribbon cable. This cable interfaces directly with the corresponding 24-Pin receptacles on both devices.

Functionality

1. Signal Extension: The 24-pin connection relays all critical signals, including power lines, GPIO control signals, I2C, SPI, and UART buses, from the Orange Pi Zero 2W's central processor to the Expansion Board.
2. Peripheral Access: The Expansion Board extends the functionality of the compact Orange Pi Zero 2W by providing access to standard external interfaces such as full-sized USB ports, an RJ45 Ethernet jack, and an audio jack.

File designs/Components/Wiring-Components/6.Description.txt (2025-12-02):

The system connects two OV5640 Camera Modules to the Orange Pi Expansion Board using a chain of components.

Dual Camera Connection via Expansion Board

1.  Camera to Bridge: The two OV5640 Camera Modules are connected via a Digital Video Port (DVP) interface to a 2 x DVP to USB Bridge board.
2.  Bridge to Expansion Board: The USB output from the Bridge board is connected via a ribbon cable to one of the 2 x USB ports on the Orange Pi Expansion Board.
3.  Data Flow: The Expansion Board, which is connected to the Orange Pi Zero 2W via a 24-pin FPC cable, acts as a hub. The USB data stream (containing video from both cameras) flows from the bridge board through the Expansion Board's USB interface and then into the Orange Pi Zero 2W for processing.

This configuration allows the Orange Pi Zero 2W to receive and process dual OV5640 camera feeds via its extended USB interface for applications requiring stereo vision or multiple viewing angles.

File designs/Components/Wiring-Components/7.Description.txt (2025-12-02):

The audio output capability of the system is realized by connecting standard earphones directly to the Orange Pi Expansion Board.

1.  Connection Point: The earphones utilize a standard 3.5mm audio jack which plugs into the corresponding 3.5mm Audio Jack located on the edge of the Orange Pi Expansion Board.
2.  Signal Path: The audio signal originates from the main Orange Pi Zero 2W board, travels through the 24-pin FPC interface to the Expansion Board, and is routed to the audio jack circuitry.
3.  Functionality: This connection allows the user to listen to audio playback directly from the Orange Pi Zero 2W system, providing the necessary human-machine interface for audio data output.

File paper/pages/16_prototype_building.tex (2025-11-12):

\subsection{Prototype Building Procedures}

% Block Diagram
% System ARchitecture

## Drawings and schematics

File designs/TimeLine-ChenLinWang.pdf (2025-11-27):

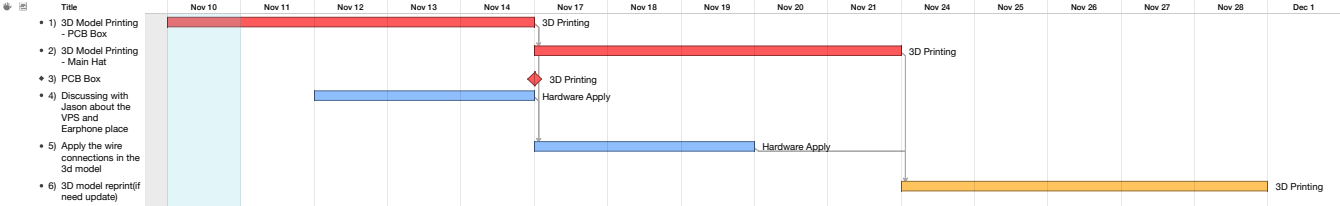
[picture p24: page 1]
3D Printing; Hardware Apply; Title; Nov 10; Nov 11; Nov 12; Nov 13; Nov 14; Nov 17; Nov 18; Nov 19; Nov 20; Nov 21; Nov 24; Nov 25; Nov 26; Nov 27; Nov 28; Dec 1

1) 3D Model Printing
- PCB Box
2) 3D Model Printing
- Main Hat
3) PCB Box
4) Discussing with
Jason about the
VPS and
Earphone place
5) Apply the wire
connections in the
3d model
6) 3D model reprint(if
need update)

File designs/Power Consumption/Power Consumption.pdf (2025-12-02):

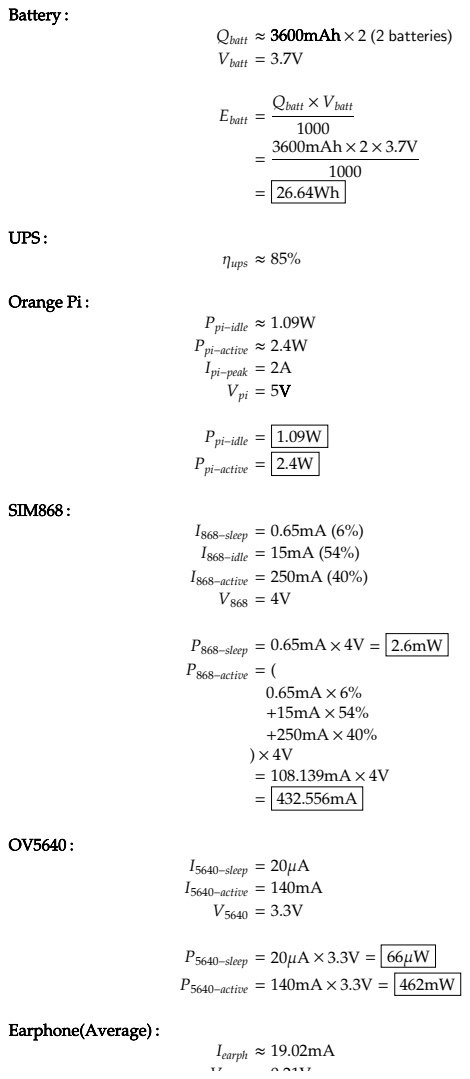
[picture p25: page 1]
Battery :; Qbatt ≈ 3600mAh × 2 (2 batteries) Vbatt = 3.7V; Ebatt = Q × V 1000; batt; = 3600mAh × 2 × 3.7V 1000; UPS :; ηups ≈ 85%; Orange Pi :; Ppi-idle ≈ 1.09W; Ppi-active ≈ 2.4W; Ipi-peak = 2A Vpi = 5V; Ppi-idle =; Ppi-active =; SIM868 :; I868-sleep = 0.65mA (6%); I868-idle = 15mA (54%); I868-active = 250mA (40%) V868 = 4V; P868-sleep = 0.65mA × 4V =; P868-active = ( 0.65mA × 6% +15mA × 54% +250mA × 40% ) × 4V = 108.139mA × 4V; I5640-sleep = 20μA; I5640-active = 140mA V5640 = 3.3V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

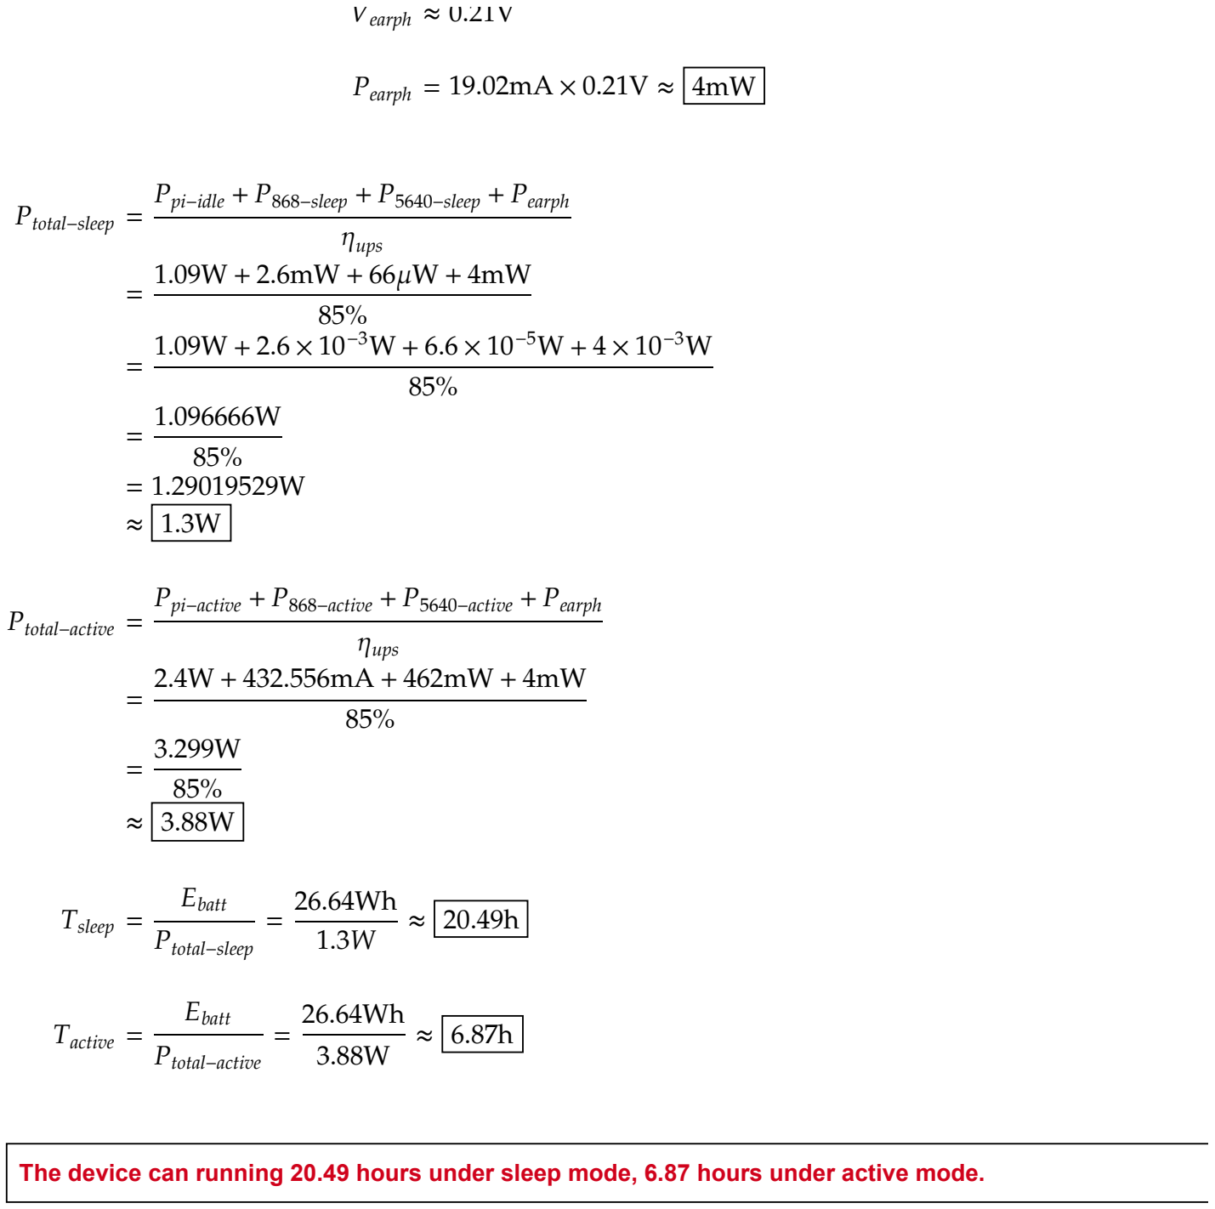
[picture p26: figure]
Vearph ≈ 0.21V; Pearph = 19.02mA × 0.21V ≈; Ptotal-sleep = P; pi-idle; 868-sleep; 5640-sleep; earph; ups = 1.09W + 2.6mW + 66μW + 4mW 85%; Ptotal-active = P; pi-active; 868-active; 5640-active; ups = 2.4W + 432.556mA + 462mW + 4mW 85%; Tsleep =; batt; total-sleep; Tactive =; total-active

= 1.09W + 2.6 × 10 W + 6.6 × 10 W + 4 × 10 W

The device can running 20.49 hours under sleep mode, 6.87 hours under active mode.

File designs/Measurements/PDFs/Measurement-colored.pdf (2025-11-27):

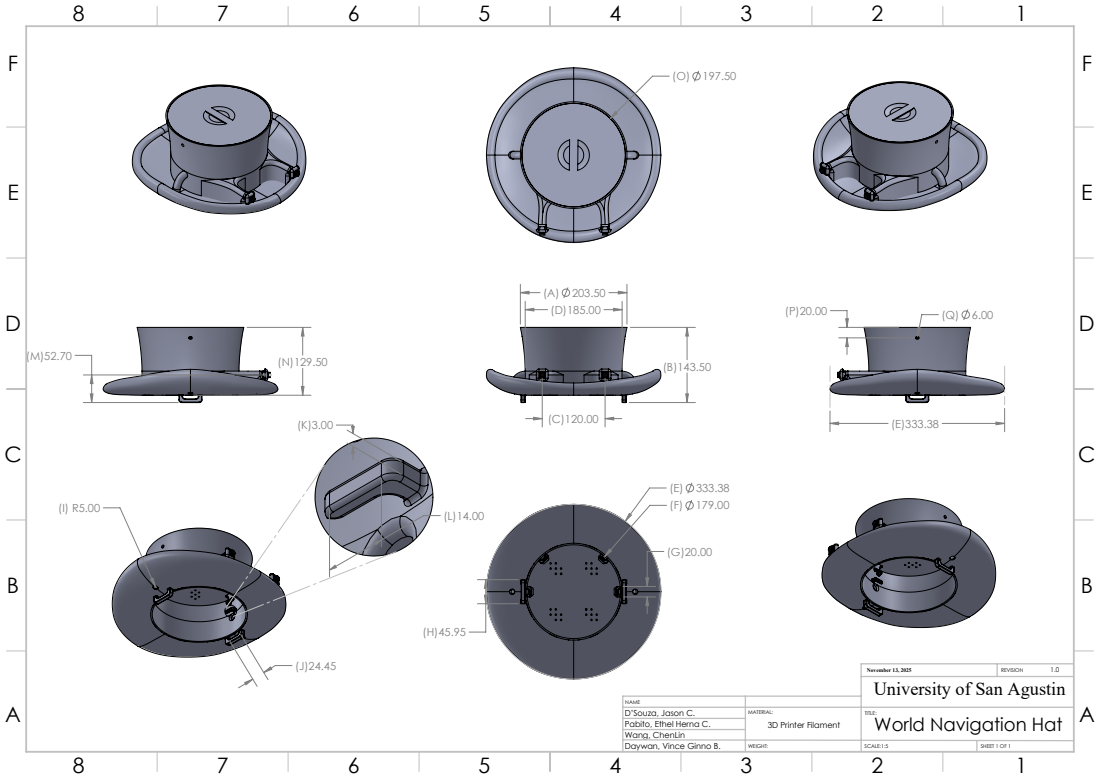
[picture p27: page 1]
November 13, 2025; REVISION; SCALE:1:5; SHEET 1 OF 1

University of San Agustin

NAME
D’Souza, Jason C. | MATERIAL: 3D Printer Filament | TITLE: World Navigation Hat

Pabito, Ethel Herna C.
Wang, ChenLin
Daywan, Vince Ginno B.

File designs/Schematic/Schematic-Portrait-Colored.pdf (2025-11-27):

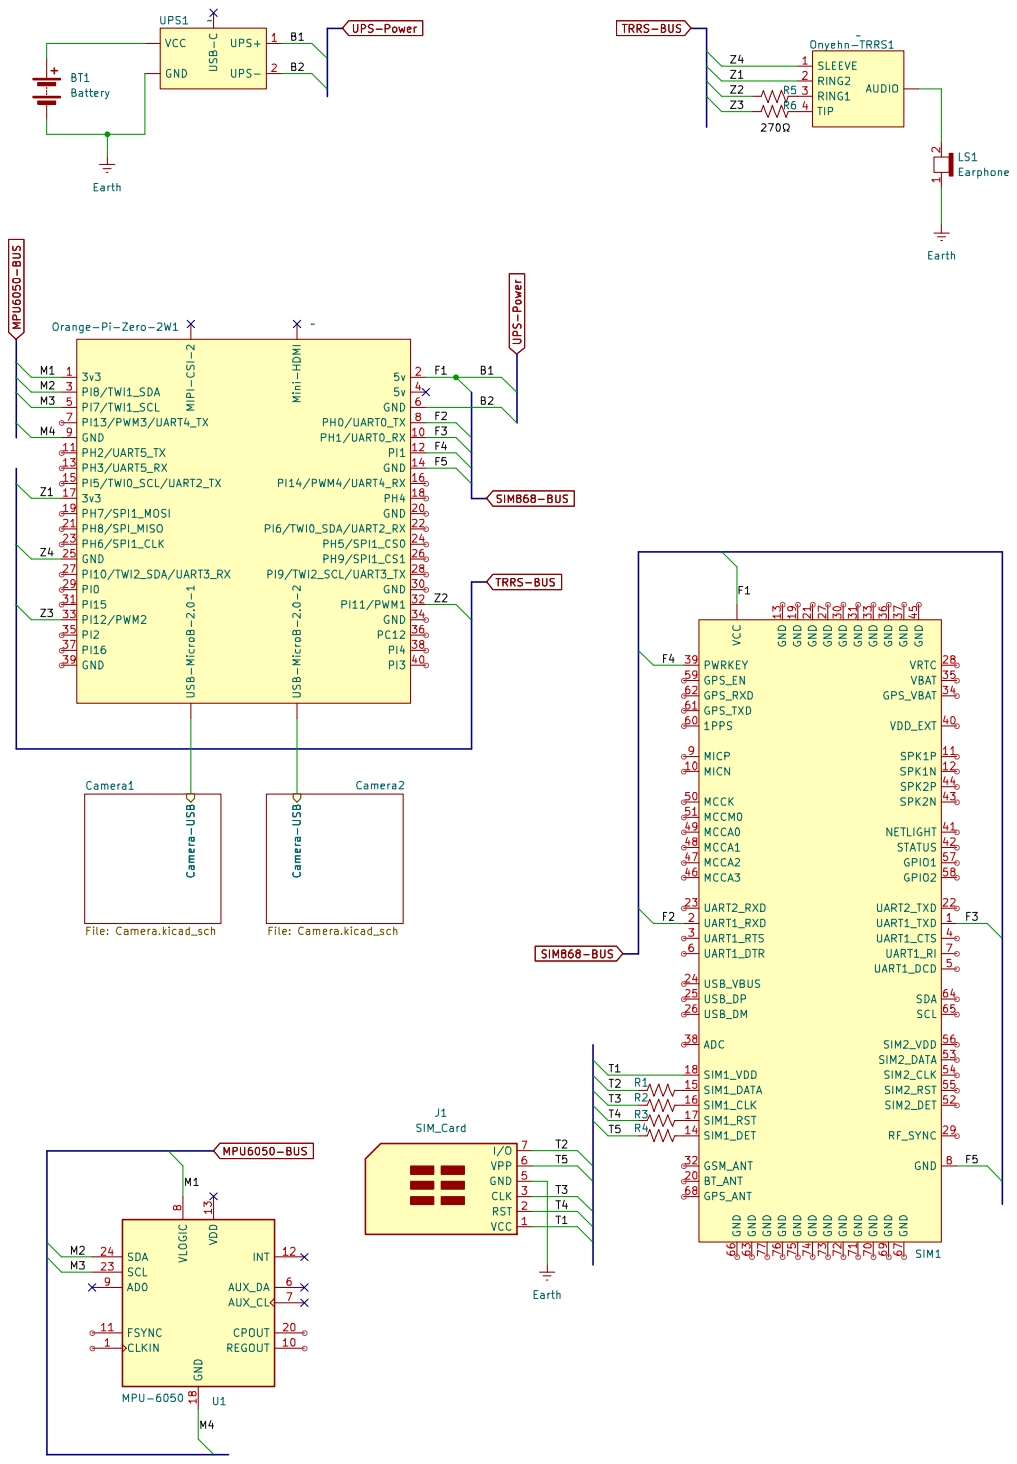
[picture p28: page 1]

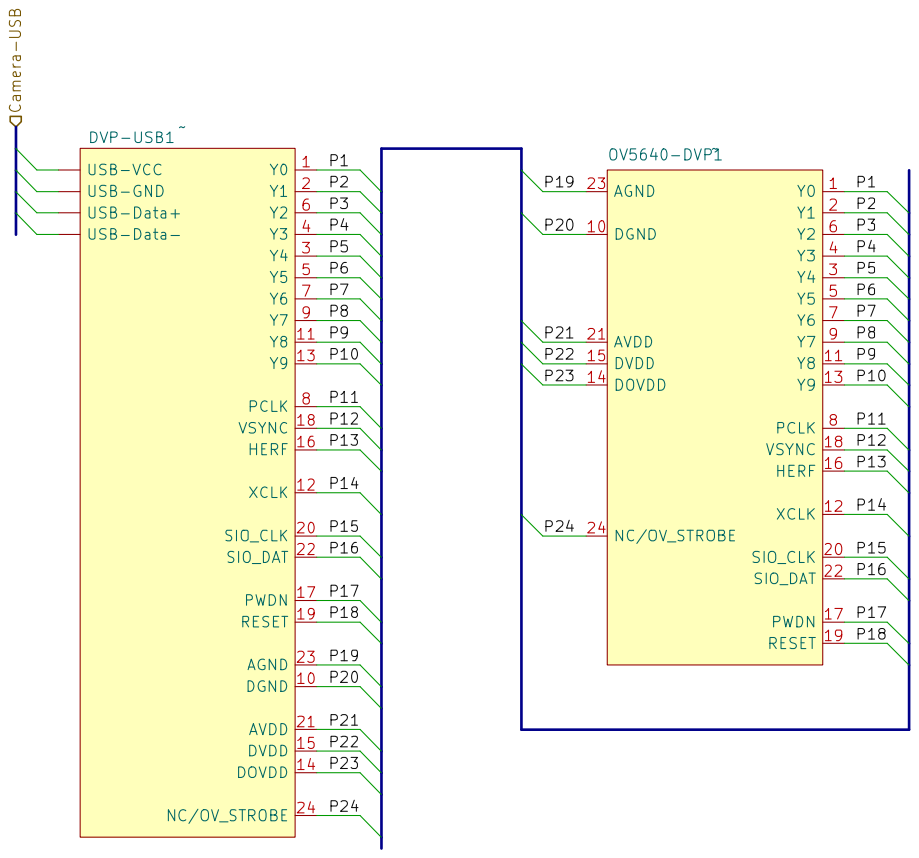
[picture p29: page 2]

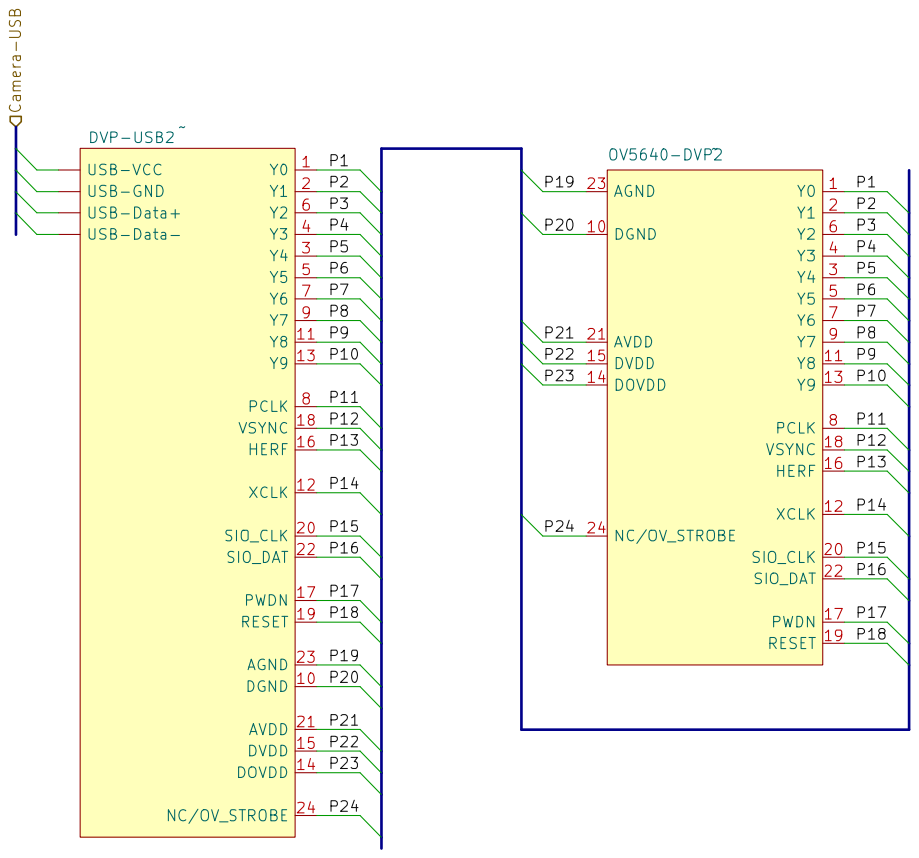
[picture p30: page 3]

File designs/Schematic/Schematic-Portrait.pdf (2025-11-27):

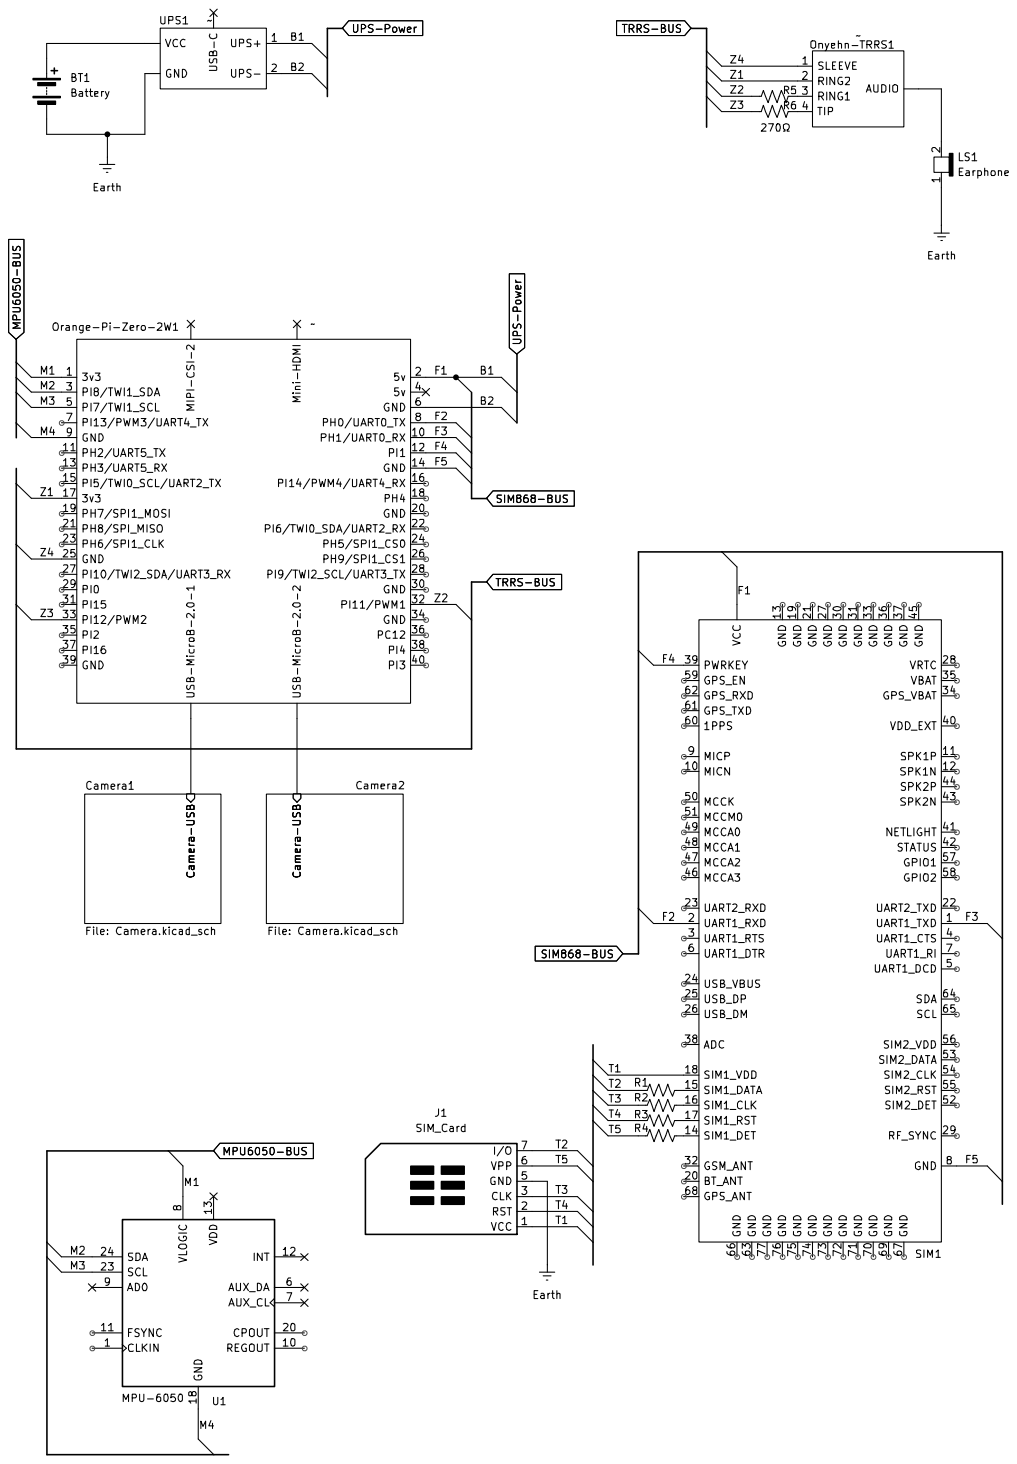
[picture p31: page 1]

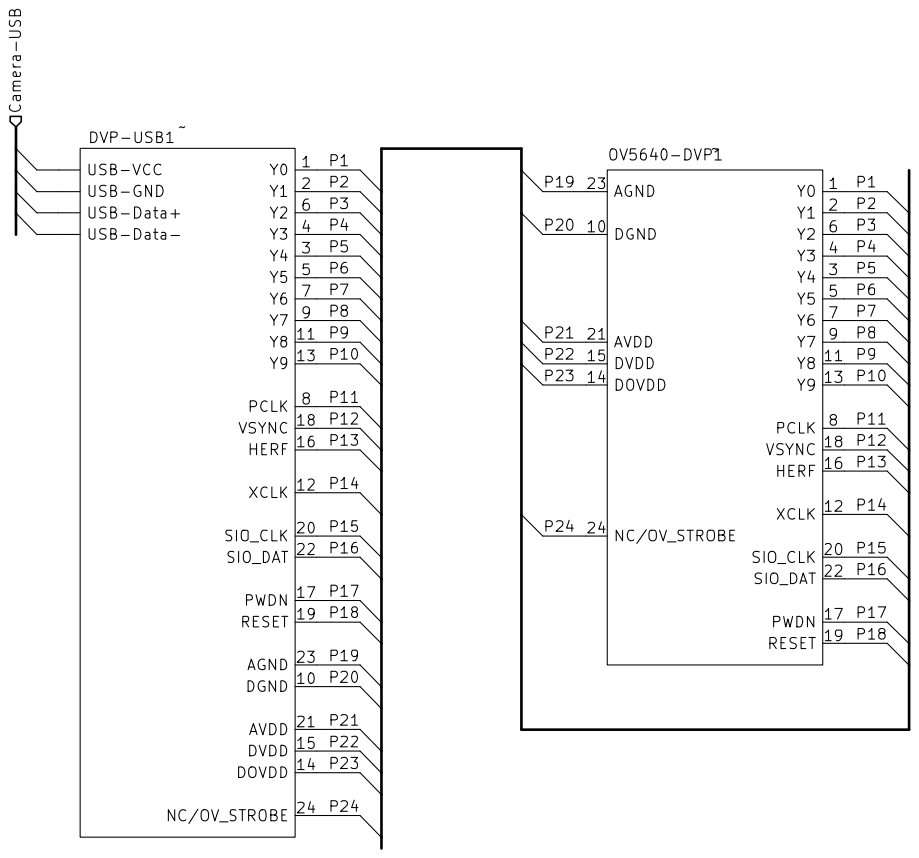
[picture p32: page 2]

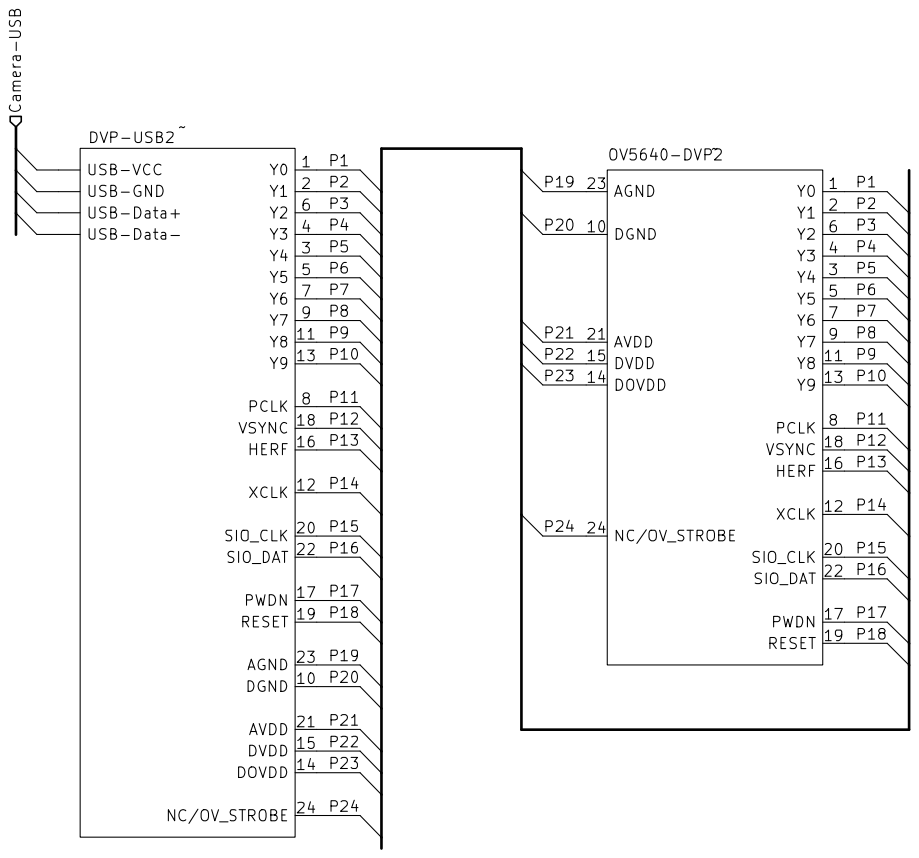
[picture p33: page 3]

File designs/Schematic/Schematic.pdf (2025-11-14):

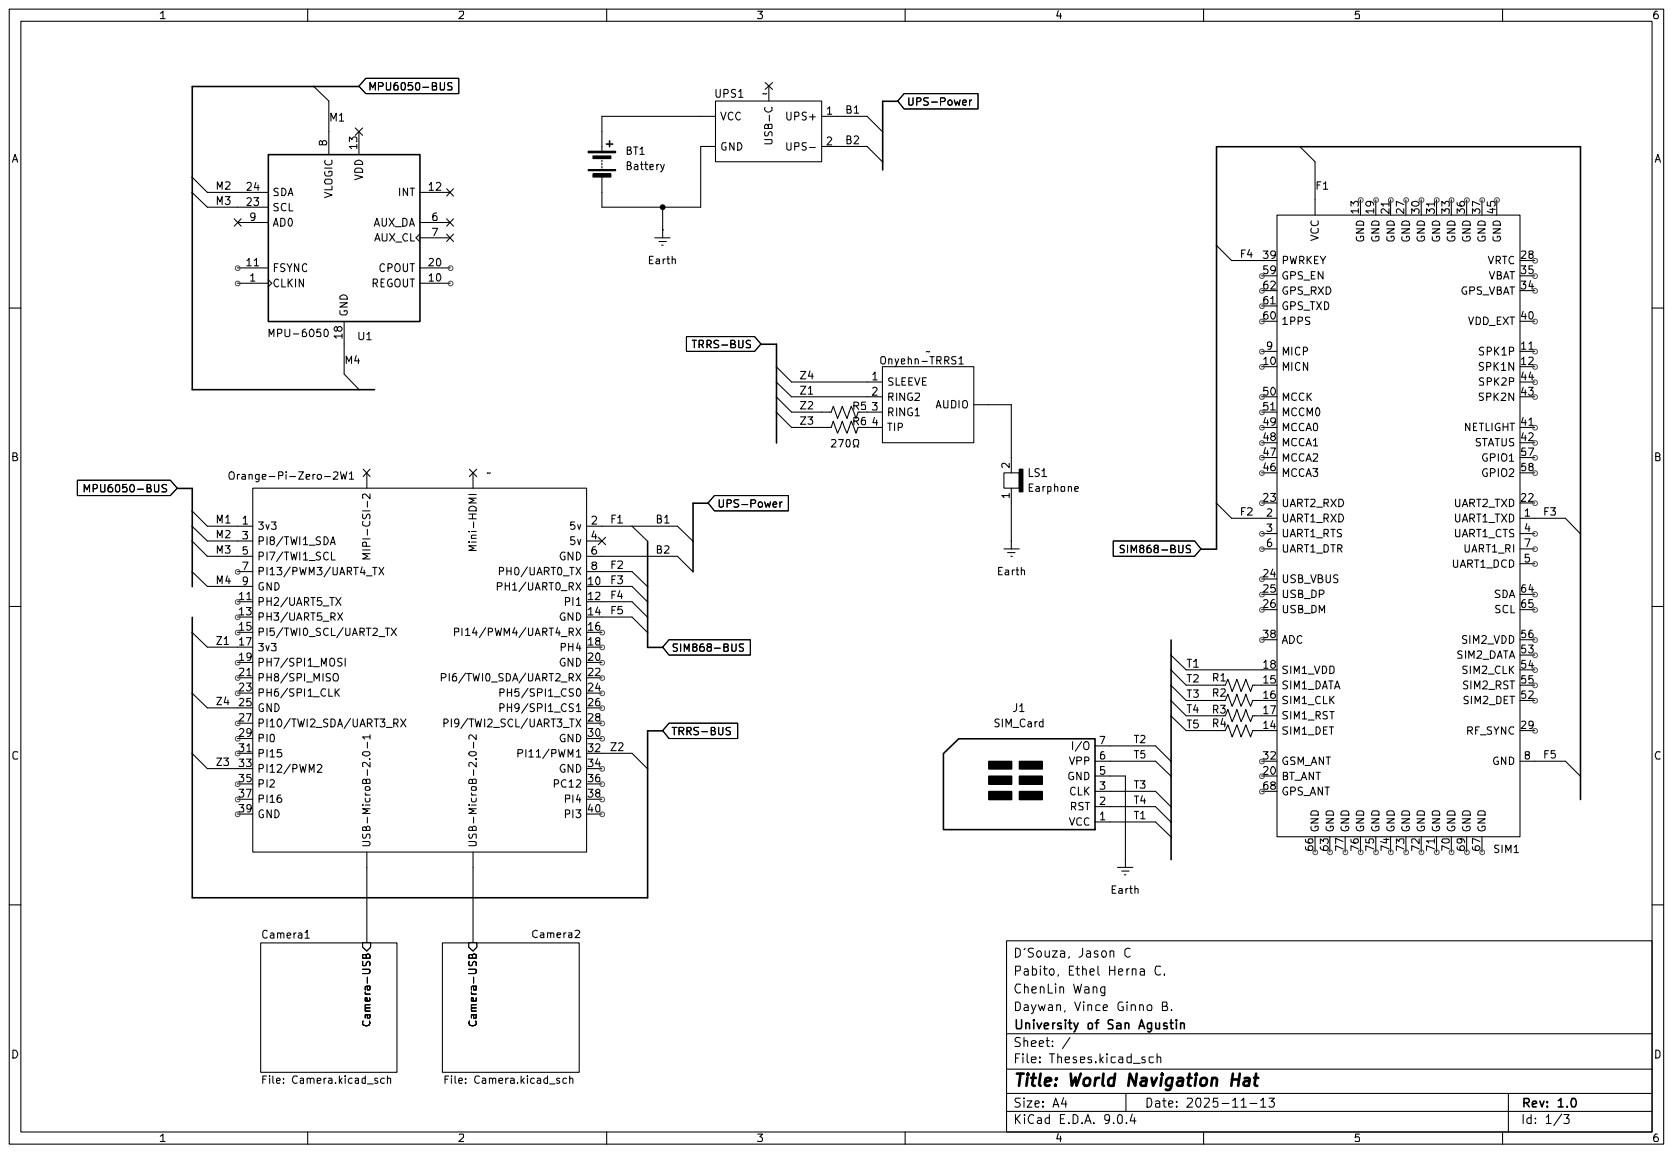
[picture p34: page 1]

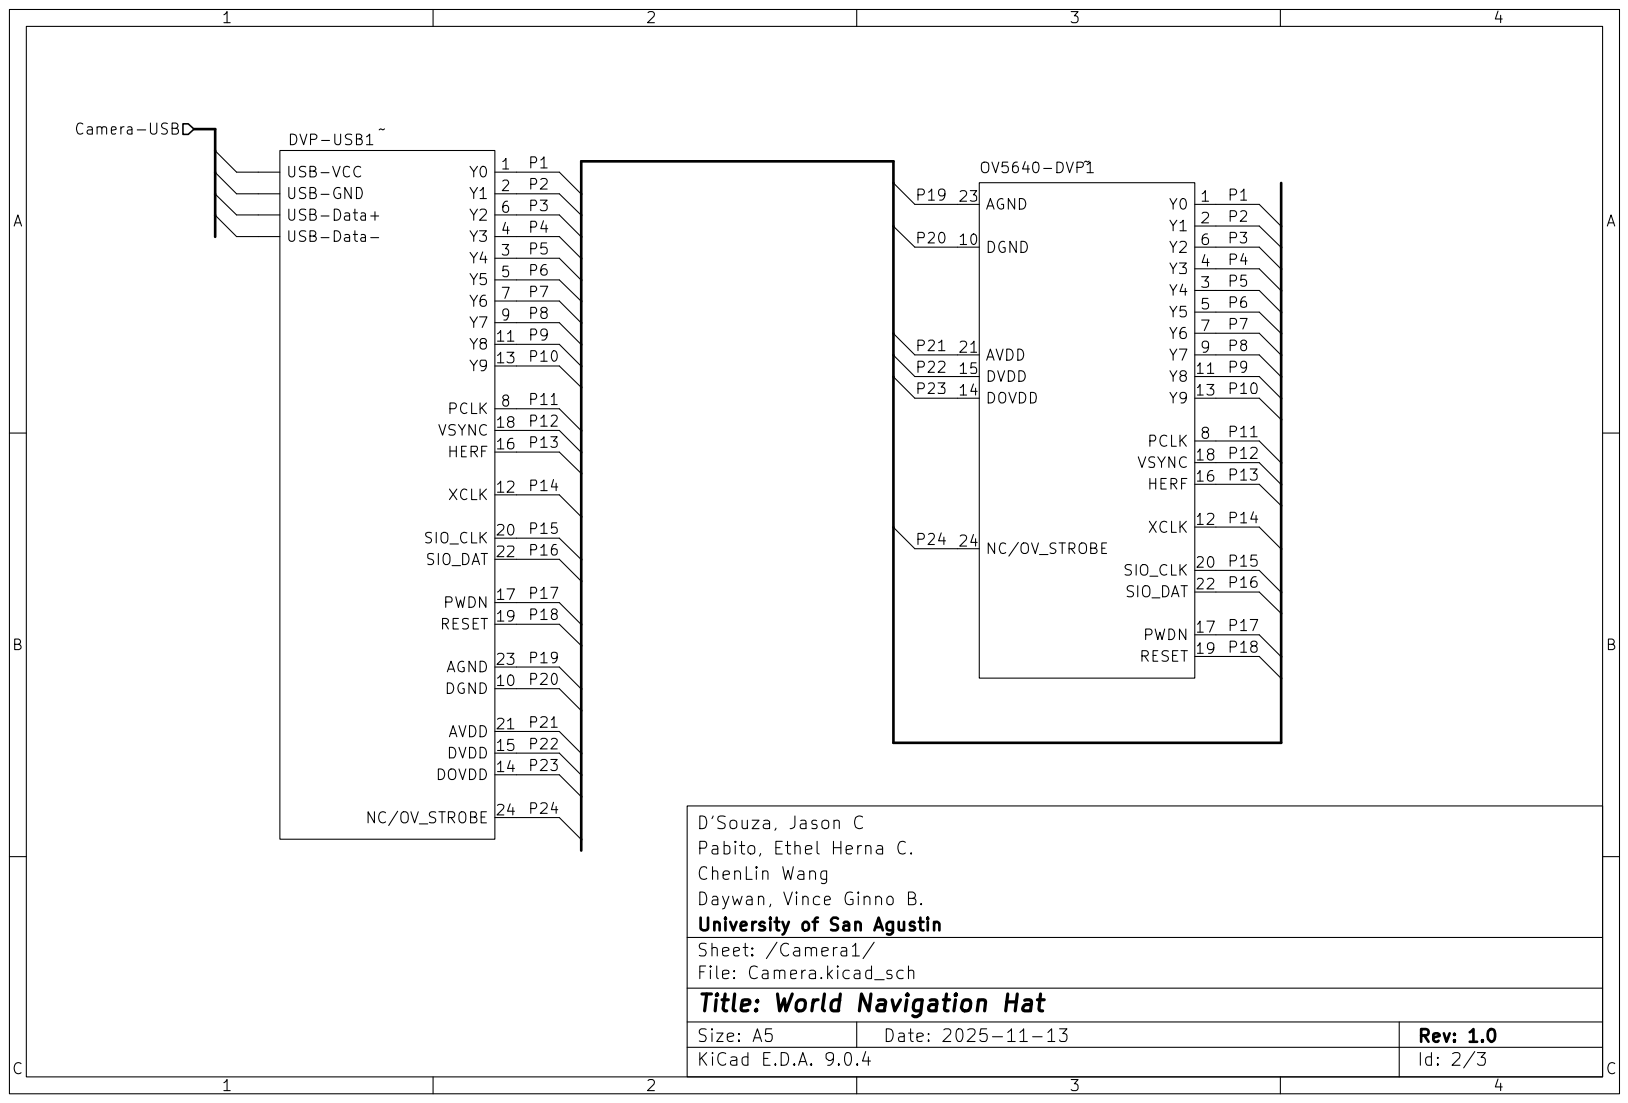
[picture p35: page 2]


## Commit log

2025-10-09 Added human sensory processes
2025-11-07 1.0.1 - Rebased prototype code from RPI5
2025-11-27 Add design models
    [0603 Capacitor.FCStd, 0603 Resistor.FCStd, 1x8 Male Header.FCStd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]
2025-11-27 Removed the kicad backup files
2025-11-28 Add Calculations of Power consumption
2025-12-02 Add: The wire connection table(Separated)
2025-12-15 1.3.5 - Device code backup
    [data.xls]
